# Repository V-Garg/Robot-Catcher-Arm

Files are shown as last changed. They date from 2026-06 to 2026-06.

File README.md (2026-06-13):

# 5-DOF Ball Interception Robotic Arm

A full-stack robotics project demonstrating real-time dynamic ball interception using a custom-designed 5-DOF robotic arm. The system integrates mechanical design, simulation, computer vision, trajectory prediction, and inverse kinematics into a complete autonomous interception pipeline.

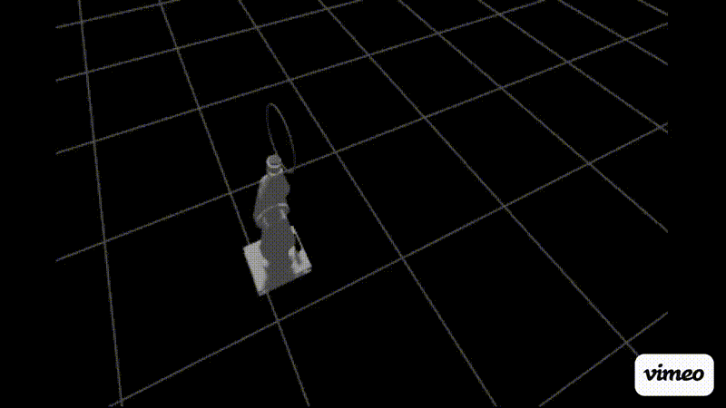
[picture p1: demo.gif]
Ball interception demo

---

## Project Overview

| Layer | Technology |
|---|---|
| CAD | SolidWorks (exported to URDF via sw2urdf) |
| Simulation | Gazebo Harmonic |
| Robot Framework | ROS2 Jazzy |
| Joint Control | ros2_control + JointTrajectoryController |
| Perception | OpenCV HSV detection + PointCloud2 depth |
| Prediction | Kalman filter + least-squares regression |
| Kinematics | Geometric analytical IK |
| Language | Python 3.12 |

---

## Mechanical Design

The arm was designed in SolidWorks with a focus on high-speed dynamic interception. All links use an oblong PETG profile for stiffness-to-weight ratio. The base uses a belt drive system with an RU124 cross-roller bearing for smooth continuous yaw rotation.

### Degrees of Freedom

| Joint | Type | Actuator | Peak Torque |
|---|---|---|---|
| J0 BaseYaw | Continuous | Flipsky 6374 140KV + HTD 5M belt | — |
| J1 ShoulderPitch | Revolute ±90° | CubeMars AK70-10 | 24.8 Nm |
| J2 ElbowPitch | Revolute ±90° | CubeMars AK60-6 V3.0 | 9.0 Nm |
| J3 WristPitch | Revolute ±90° | CubeMars AK40-10 | 4.1 Nm |
| J4 HoopRotate | Continuous | CubeMars AK40-10 | 4.1 Nm |

### Link Lengths

```
L1 (base to shoulder):  0.207 m
L2 (shoulder to elbow): 0.250 m
L3 (elbow to wrist):    0.250 m
L4 (wrist to hoop):     0.184 m
Max reach:              0.684 m
```

### End Effector

235mm diameter hoop with a simulated net (zero-bounce, high-friction collision cylinder) that catches the ball on contact and prevents it from bouncing out.

---

## Software Architecture

```
Gazebo Simulation
      │
      ├── /camera/color/image_raw      ──► ball_detector.py
      ├── /camera/depth/image_raw/points──► ball_detector.py
      │
      └── ball_detector.py
              │ /ball_position (camera_optical frame)
              ▼
      trajectory_predictor.py
              │  TF: camera_optical → world
              │  Kalman filter [x,y,z,vx,vy,vz]
              │  Least-squares velocity regression
              │  Parabolic intercept prediction
              │ /ball_intercept_point (world frame)
              ▼
      ik_solver.py
              │  Confidence gating (stable prediction window)
              │  Geometric analytical IK
              │  Corrected joint direction signs
              │ /arm_controller/joint_trajectory
              ▼
      JointTrajectoryController
              │
              └── Gazebo physics simulation
```

---

## Perception Pipeline

### Ball Detection (`scripts/ball_detector.py`)

- Subscribes to `/camera/color/image_raw` and `/camera/depth/image_raw/points`
- Detects orange ball using dual HSV masks (normal + shadow range)
- Samples a 5×5 pixel patch around the detected centroid for robust depth
- Reads raw PointCloud2 bytes directly with `struct.unpack_from` (numpy-version-safe)
- Publishes ball 3D position in `camera_optical` frame to `/ball_position`

### Trajectory Prediction (`scripts/trajectory_predictor.py`)

- Transforms ball positions from `camera_optical` → `world` via TF
- Runs a 6-state Kalman filter `[x, y, z, vx, vy, vz]`
- Blends Kalman velocity (60%) with weighted least-squares window regression (40%) for faster convergence
- Detects ball jumps > 30cm and resets filter (handles pick-up/respawn)
- Dynamically computes intercept time by scanning for earliest moment the ball is within arm reach and above ground
- Applies full parabolic prediction: `z(t) = z₀ + vz·t - ½g·t²`
- Publishes to `/ball_intercept_point` in world frame

### IK Solver (`scripts/ik_solver.py`)

- Waits for 3 consecutive stable predictions within 12cm spread before commanding
- Geometric analytical IK calibrated from TF measurements:
  - BaseYaw: `j0 = atan2(-tx, -ty)` (positive = clockwise from above)
  - ElbowPitch: `j2 = π - arccos(cos_j2)` (positive = inward bend)
  - ShoulderPitch: `j1 = -(alpha - beta)` (negative = forward)
  - WristPitch: `j3 = -(j1 + j2)` (keeps hoop level)
- Only resends command if intercept shifts > 15cm from last commanded position
- Minimum 250ms between commands to prevent motion interruption

---

## Simulation Setup

### World Configuration (`worlds/ball_world.sdf`)

- Physics: Gazebo Harmonic with ODE, `real_time_factor=0.5`
- Collision bitmasks:
  - Arm links: `0x01` (collide with ball only, not ground)
  - Ground plane: `0x02`
  - Ball: `0x03` (collides with everything)
- Orange ball: 0.067m radius, mass 0.15kg, restitution 0.7

### Camera (`urdf/arm.urdf`)

Simulated Intel RealSense D435 mounted on the base:
- Color camera: 640×480, 30Hz, 87° FOV
- Depth camera: 640×480, ~22Hz, R_FLOAT32 format, 0.1–5.0m range
- A `camera_optical` TF frame corrects sensor orientation for point cloud alignment

### Controllers (`config/controllers.yaml`)

Uses `JointTrajectoryController` in position mode at 1000Hz update rate with `interpolate_from_desired_state: true`.

Joint gains (set via `position_proportional_gain` in ros2_control hardware interface):
- BaseYaw: 5.0 (higher — carries full arm inertia)
- All others: 2.0

---

## Repository Structure

```
arm/
├── urdf/
│   └── arm.urdf              # Full robot description
├── meshes/
│   ├── base_link.STL
│   ├── Shoulder.STL
│   ├── UpperArm.STL
│   ├── LowerArm.STL
│   ├── Wrist.STL
│   ├── Hoop.STL
│   └── Camera.STL
├── worlds/
│   └── ball_world.sdf        # Gazebo simulation world
├── config/
│   └── controllers.yaml      # ros2_control configuration
├── launch/
│   └── gazebo.launch.py      # Full system launch
├── scripts/
│   ├── ball_detector.py      # Vision perception node
│   ├── trajectory_predictor.py # Kalman filter + prediction
│   └── ik_solver.py          # Geometric IK + arm control
├── CMakeLists.txt
├── package.xml
└── README.md
```

---

## Requirements

### System

- Ubuntu 24.04
- ROS2 Jazzy
- Gazebo Harmonic

### ROS2 Packages

```bash
sudo apt install \
  ros-jazzy-gz-ros2-control \
  ros-jazzy-ros2-control \
  ros-jazzy-ros2-controllers \
  ros-jazzy-ros-gz \
  ros-jazzy-ros-gz-bridge \
  ros-jazzy-cv-bridge \
  ros-jazzy-sensor-msgs-py \
  ros-jazzy-tf2-geometry-msgs \
  python3-opencv
```

---

## Installation

```bash
# Create a workspace (if you don't already have one)
mkdir -p ~/ros2_ws/src
cd ~/ros2_ws/src

# Clone the repository git
clone https://github.com/V-Garg/Robot-Catcher-Arm.git

# Build
cd ~/ros2_ws
colcon build --symlink-install

# Source
source /opt/ros/jazzy/setup.bash
source ~/ros2_ws/install/setup.bash

# Set environment variables
export GZ_SIM_RESOURCE_PATH=$GZ_SIM_RESOURCE_PATH:$HOME/ros2_ws/install/arm/share
export GZ_SIM_SYSTEM_PLUGIN_PATH=$GZ_SIM_SYSTEM_PLUGIN_PATH:/opt/ros/jazzy/lib

# Fix snap/libpthread conflict if needed (NVIDIA GPU systems)
export LD_LIBRARY_PATH=$(echo $LD_LIBRARY_PATH | tr ':' '\n' | grep -v snap | tr '\n' ':')
```

---

## Running

```bash
ros2 launch arm gazebo.launch.py
```

This single command starts:
1. Gazebo with ball world
2. Robot state publisher
3. ROS2-Gazebo topic bridge
4. Arm spawn
5. Joint state broadcaster (t+8s)
6. Arm trajectory controller (t+10s)
7. Ball detector node (t+12s)
8. Trajectory predictor (t+13s)
9. IK solver (t+14s)

Once running, throw the ball in Gazebo toward the arm. The system will detect the ball, predict its trajectory, and move the hoop to intercept it.

---

## Key Design Decisions

**Why analytical IK over numerical?**
The arm's joint axes are non-trivial due to SolidWorks export RPY values. After calibrating joint directions from TF measurements, geometric IK gives deterministic fast solutions without iteration overhead critical for real-time interception.

**Why blend Kalman with regression?**
Pure Kalman takes 10+ frames to converge on velocity. Weighted least-squares regression over a rolling 8-frame window gives accurate velocity estimates within 4 frames, blended 40/60 with Kalman for noise rejection.

**Why confidence gating?**
Streaming raw IK commands causes the arm to overshoot and oscillate as it chases noisy early predictions. Waiting for 3 predictions within 12cm spread ensures the arm commits to a single confident motion rather than constantly correcting.

**Why collision bitmasks?**
The arm's geometry clips below ground level due to the SolidWorks coordinate origin. Bitmasks decouple arm-ground collision while preserving ball-arm and ball-ground interaction.

---

## Author

Vaibhav Garg — Computer Engineering, University of Maryland College Park (May 2026)

Built as a portfolio project demonstrating full-stack robotics engineering across mechanical design, simulation, perception, and control.

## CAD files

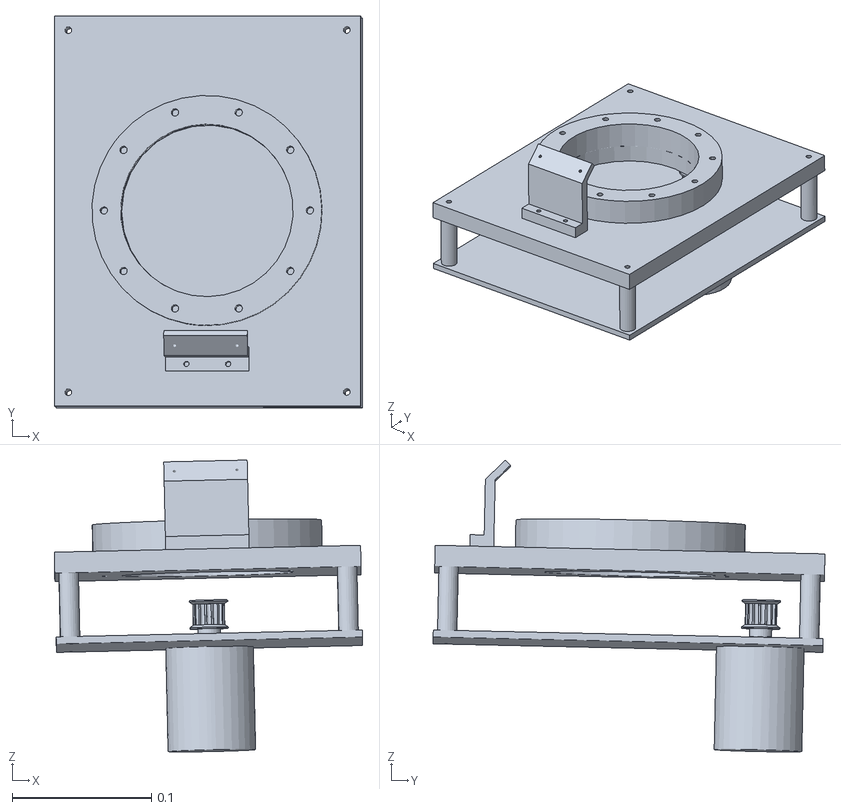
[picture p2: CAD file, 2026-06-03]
meshes/base_link.STL
0.221 x 0.281 x 0.21

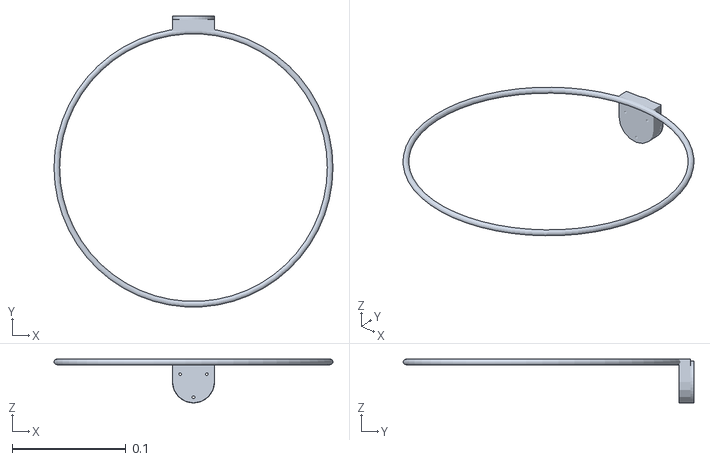
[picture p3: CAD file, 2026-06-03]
meshes/Hoop.STL
0.245 x 0.255 x 0.0385

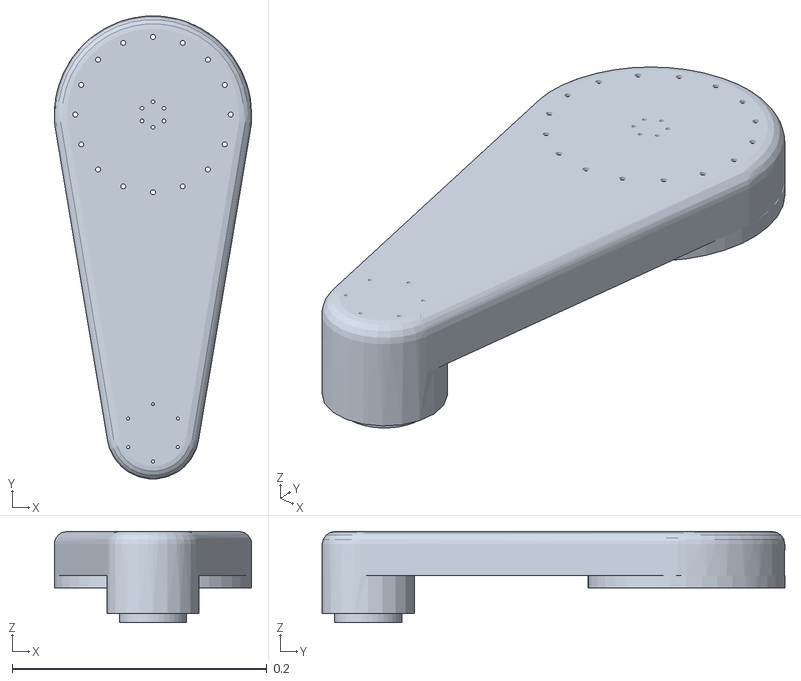
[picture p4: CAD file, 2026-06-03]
meshes/LowerArm.STL
0.155 x 0.364 x 0.0715

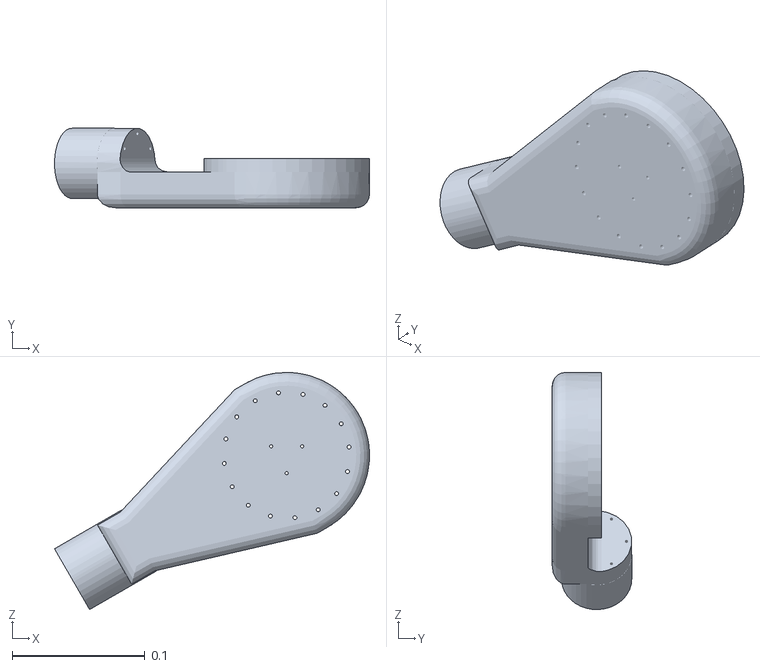
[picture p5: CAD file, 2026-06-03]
meshes/Wrist.STL
0.238 x 0.06 x 0.179

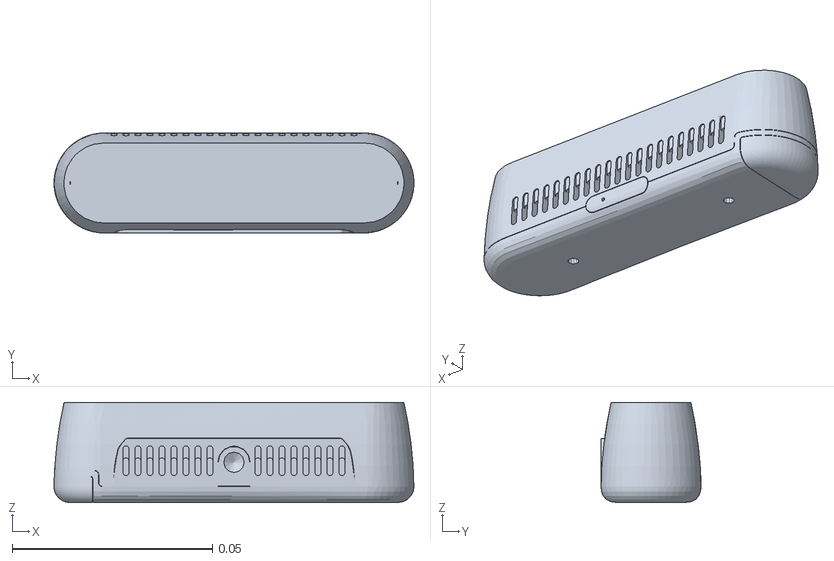
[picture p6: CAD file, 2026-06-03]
meshes/Camera.STL
0.09 x 0.025 x 0.025

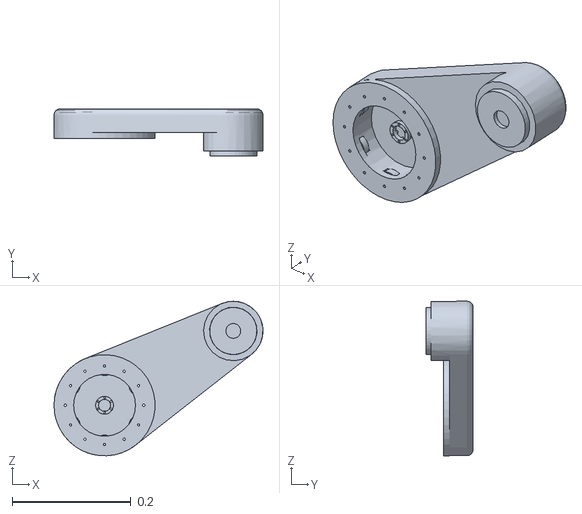
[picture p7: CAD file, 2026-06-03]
meshes/UpperArm.STL
0.351 x 0.0795 x 0.26

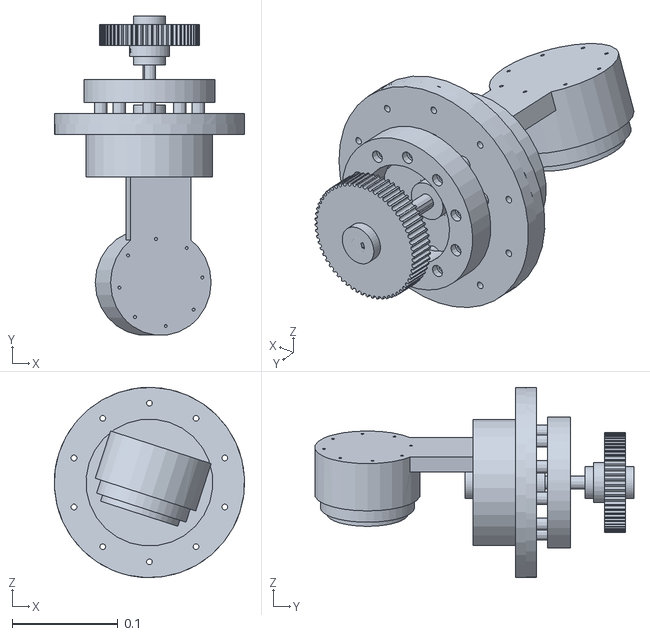
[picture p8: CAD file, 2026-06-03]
meshes/Shoulder.STL
0.18 x 0.302 x 0.18

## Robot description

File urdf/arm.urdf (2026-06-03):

<?xml version="1.0" encoding="utf-8"?>
<robot name="arm">

  <link name="world"/>

  <joint name="world_fixed" type="fixed">
    <parent link="world"/>
    <child link="base_link"/>
    <origin xyz="0 0 0" rpy="0 0 0"/>
  </joint>

  <ros2_control name="arm_hardware" type="system">
    <hardware>
      <plugin>gz_ros2_control/GazeboSimSystem</plugin>
    </hardware>
    <joint name="BaseYaw">
      <command_interface name="position">
        <param name="position_proportional_gain">5.0</param>
      </command_interface>
      <state_interface name="position"/>
      <state_interface name="velocity"/>
    </joint>
    <joint name="ShoulderPitch">
      <command_interface name="position">
        <param name="position_proportional_gain">2.0</param>
      </command_interface>
      <state_interface name="position"/>
      <state_interface name="velocity"/>
    </joint>
    <joint name="ElbowPitch">
      <command_interface name="position">
        <param name="position_proportional_gain">2.0</param>
      </command_interface>
      <state_interface name="position"/>
      <state_interface name="velocity"/>
    </joint>
    <joint name="WristPitch">
      <command_interface name="position">
        <param name="position_proportional_gain">2.0</param>
      </command_interface>
      <state_interface name="position"/>
      <state_interface name="velocity"/>
    </joint>
    <joint name="HoopRotate">
      <command_interface name="position">
        <param name="position_proportional_gain">2.0</param>
      </command_interface>
      <state_interface name="position"/>
      <state_interface name="velocity"/>
    </joint>
  </ros2_control>

  <link name="base_link"/>

  <joint name="base_link_to_base_body" type="fixed">
    <parent link="base_link"/>
    <child link="base_body"/>
    <origin xyz="0 0 0" rpy="0 0 0"/>
  </joint>

  <link name="base_body">
    <inertial>
      <origin xyz="0.000363 -0.016407 -0.013656" rpy="0 0 0"/>
      <mass value="4.0693408144362"/>
      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
    </inertial>
    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
  </link>

  <joint name="BaseYaw" type="continuous">
    <origin xyz="0 0 0" rpy="-1.5569 -0.028316 -1.2307"/>
    <parent link="base_link"/>
    <child link="Shoulder"/>
    <axis xyz="0 1 0"/>
    <limit effort="32.0" velocity="10.0"/>
    <dynamics damping="2.0" friction="0.0"/>
  </joint>

  <link name="Shoulder">
    <inertial>
      <origin xyz="0.000158 -0.095156 0.000474" rpy="0 0 0"/>
      <mass value="3.12266982777306"/>
      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
    </inertial>
    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
  </link>

  <joint name="ShoulderPitch" type="revolute">
    <origin xyz="0 -0.207 0" rpy="-1.84 -0.16389 -2.1048"/>
    <parent link="Shoulder"/>
    <child link="UpperArm"/>
    <axis xyz="0 1 0"/>
    <limit lower="-1.57" upper="1.57" effort="24.8" velocity="6.0"/>
    <dynamics damping="1.5" friction="0.0"/>
  </joint>

  <link name="UpperArm">
    <inertial>
      <origin xyz="0.109556 0.014861 0.063252" rpy="0 0 0"/>
      <mass value="2.95618459814663"/>
      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
    </inertial>
    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
  </link>

  <joint name="ElbowPitch" type="revolute">
    <origin xyz="0.21651 0 0.125" rpy="-1.5708 -1.0086 -3.1416"/>
    <parent link="UpperArm"/>
    <child link="LowerArm"/>
    <axis xyz="0 0 1"/>
    <limit lower="-1.57" upper="1.57" effort="9.0" velocity="8.0"/>
    <dynamics damping="0.1" friction="0.0"/>
  </joint>

  <link name="LowerArm">
    <inertial>
      <origin xyz="1.73E-07 -0.114308 0.022476" rpy="0 0 0"/>
      <mass value="1.89340928996277"/>
      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
    </inertial>
    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
  </link>

  <joint name="WristPitch" type="revolute">
    <origin xyz="0 -0.25 0" rpy="1.5708 0 2.1458"/>
    <parent link="LowerArm"/>
    <child link="Wrist"/>
    <axis xyz="0 1 0"/>
    <limit lower="-1.57" upper="1.57" effort="4.1" velocity="10.0"/>
    <dynamics damping="0.1" friction="0.0"/>
  </joint>

  <link name="Wrist">
    <inertial>
      <origin xyz="-0.058969 -0.016427 -0.034046" rpy="0 0 0"/>
      <mass value="0.913494263645654"/>
      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
    </inertial>
    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
  </link>

  <joint name="HoopRotate" type="continuous">
    <origin xyz="-0.15912 -0.00405 -0.091868" rpy="0.52375 0.023075 -1.5575"/>
    <parent link="Wrist"/>
    <child link="Hoop"/>
    <axis xyz="0 1 0"/>
    <limit effort="5.0" velocity="15.0"/>
    <dynamics damping="0.1" friction="0.0"/>
  </joint>

  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
  <link name="Hoop">
    <inertial>
      <origin xyz="-1.44E-07 -0.062493 0.008432" rpy="0 0 0"/>
      <mass value="0.0430752676223343"/>
      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
    </inertial>
    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
  </link>

  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
  <link name="Camera">
    <inertial>
      <origin xyz="0.000246 -6.06E-05 -0.013048" rpy="0 0 0"/>
      <mass value="0.120833728236314"/>
      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
    </inertial>
    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
  </link>

  <joint name="FixedCamera" type="fixed">
    <origin xyz="-0.0020245 -0.1136 0.092255" rpy="0.76332 -0.022515 0.00046617"/>
    <parent link="base_link"/>
    <child link="Camera"/>
  </joint>

  <link name="camera_optical"/>

  <joint name="camera_to_optical" type="fixed">
    <parent link="Camera"/>
    <child link="camera_optical"/>
    <origin xyz="0 0 0" rpy="0 -1.5707 -1.5707"/>
  </joint>

  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

</robot>

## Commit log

2026-06-03 Initial commit: 5-DOF ball interception arm
    [Camera.STL, Hoop.STL, LowerArm.STL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]
2026-06-03 Enhance README with arm functionality details
    Added a note about the arm's functionality in ball interception.
